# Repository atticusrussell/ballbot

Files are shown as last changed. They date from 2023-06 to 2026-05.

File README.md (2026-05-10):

# BallBot




A 4WD differential-drive robot running ROS 2 Humble that detects pickleballs on a court, navigates to them, picks them up with an onboard 6-DOF arm, and returns them to a base station — all while staying outside the court boundary so it doesn't get stepped on.

The original v1 platform paired a Raspberry Pi 4 with a Teensy 4.1 (motor/encoder/IMU via [linorobot2](https://github.com/linorobot/linorobot2)), an RPLIDAR A1, and a USB webcam. The v2 redesign in progress swaps in a Jetson Orin Nano Super, a DOFBOT-SE 6-DOF arm, and an rpicam3.

**Status**: v2 in active development. See:
- [`docs/ARCHITECTURE.md`](docs/ARCHITECTURE.md) — system design, node graph, TF tree, open architectural questions
- [`docs/ROADMAP.md`](docs/ROADMAP.md) — milestone breakdown
- [GitHub Project: Ballbot](https://github.com/users/atticusrussell/projects/6) — live progress

## Hardware

#### Front view


#### Side view


#### Rear top view


#### Initial construction


### v1 part list

| | Part |
| --| --|
|1| [Raspberry Pi 4 (4 GB)](https://www.raspberrypi.com/products/raspberry-pi-4-model-b/) — *being replaced by Jetson Orin Nano Super in v2*|
|2| [AmazonBasics 128 GB SD Card](https://www.amazon.com/dp/B08TJRVWV1)|
|3| [Yahboom Aluminum 4WD ROS Robot Car Chassis](https://category.yahboom.net/collections/a-chassis-bracket/products/ros-chassis)|
|4| [L298N Motor Drivers](https://www.amazon.com/dp/B07BK1QL5T)|
|5| [DFRobot DC-DC Power Module 25W DFR0205](https://www.digikey.com/en/products/detail/dfrobot/DFR0205/6588491)|
|6| [Screw-down Terminal Block Strips](https://www.amazon.com/dp/B08V4W637Q)|
|7| [RPLIDAR A1](https://www.slamtec.com/en/Lidar/A1)|
|8| [GeeekPi Fan Hat with OLED](https://www.amazon.com/dp/B09MVL8BWQ)|
|9| Teensy 4.1 (running [linorobot2_hardware](https://github.com/linorobot/linorobot2_hardware))|
|10| Various standoffs, wires, and crimped connectors|

### v2 additions (in progress)

- Jetson Orin Nano Super (compute upgrade)
- DOFBOT-SE 6-DOF arm + gripper (manipulation)
- Raspberry Pi Camera Module 3 (CSI, replacing the USB webcam)

See `ARCHITECTURE.md` for the full v2 hardware story including the open question on whether to bypass the DOFBOT STM32 expansion board and drive it directly over I2C from the Orin.

## Development

The project builds and runs in the VSCode devcontainers under `.devcontainer/`. Pick the variant matching your host:

- `linux-gpu/` — Linux host with NVIDIA GPU
- `wsl-gpu/` — WSL 2 with GPU passthrough

For GPU passthrough you'll first need the [NVIDIA Container Toolkit](https://docs.nvidia.com/datacenter/cloud-native/container-toolkit/latest/install-guide.html).

## Acknowledgments

- [Allison Thackston](https://github.com/athackst/vscode_ros2_workspace) — workspace template
- [Articulated Robotics](https://articulatedrobotics.xyz/) — tutorials
- [Lidarbot](https://github.com/TheNoobInventor/lidarbot)
- [linorobot2](https://github.com/linorobot/linorobot2) and [linorobot2_hardware](https://github.com/linorobot/linorobot2_hardware) — base platform
- [ros2_rover](https://github.com/mgonzs13/ros2_rover/)

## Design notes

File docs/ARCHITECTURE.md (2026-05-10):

# BallBot v2 Architecture

Reference architecture for the v2 redesign — pickleball ball-retrieval robot with onboard arm, swap from RPi 4 to Jetson Orin Nano Super, indoor + outdoor (court) operation.

This document is the source of truth for system structure. Per-phase task tracking lives in GitHub Issues / Milestones.

> **Naming policy**: the robot's name in prose is **BallBot**, and ROS packages use the `ballbot_` prefix (`ballbot_description`, `ballbot_navigation`, etc.).

---

## 1. System overview

The robot is a 4WD differential-drive base with a 6-DOF arm + gripper mounted on top. It localizes against a 2D lidar map indoors, and against pickleball-court line geometry outdoors (where lidar fails). A learned object detector finds pickleballs in the camera feed; a Behavior Tree orchestrates "find ball → drive to ball → grasp → return to base" while respecting a court keep-out polygon.

```mermaid
flowchart LR
    subgraph Perception
        CAM[Chassis camera] --> DET[Pickleball detector<br/>YOLO + TensorRT]
        CAM --> VO[Visual odometry<br/>court-line PnP]
        EIH[Eye-in-hand camera] --> VS[Visual servoing]
        LIDAR[RPLIDAR A1] --> SLAM[SLAM Toolbox / AMCL]
    end

    subgraph Localization
        SLAM --> EKF
        VO --> EKF
        WHEEL[Wheel odom + IMU] --> EKF[robot_localization EKF]
    end

    subgraph Planning
        EKF --> NAV[nav2 stack]
        DET --> BT[Behavior Tree]
        COURT[Court polygon publisher] --> NAV
        BT --> NAV
        BT --> ARM[Arm action server]
    end

    subgraph Control
        NAV --> TWIST[twist_mux]
        TWIST --> BASE[linorobot2_base / Teensy]
        VS --> ARM
        ARM --> SERVOS[DOFBOT-SE servos]
    end
```

---

## 2. Node graph + per-phase deltas

### Baseline (current state, post-revival)

```mermaid
flowchart LR
    teensy[linorobot_base<br/>Teensy] -->|/odom_raw| ekf[ekf_filter_node]
    imu[/imu/data/] --> ekf
    ekf -->|/odom + tf odom→base_link| nav[nav2]
    lidar[rplidar_node] -->|/scan| slam[slam_toolbox<br/>or amcl]
    slam -->|map→odom tf| nav
    nav -->|/cmd_vel| mux[twist_mux]
    joy[joy_teleop] -->|/cmd_vel_joy| mux
    mux -->|/cmd_vel_muxed| teensy
    cam[v4l2_camera] -->|/camera/image_raw| balltrack[ball_tracker<br/>color-blob, legacy]
```

### Adds in M1A/M1B (sim + real nav)

No new nodes — just tuning + map. nav2 + AMCL come up reliably.

### Adds in M2A/M2B (detector)

```mermaid
flowchart LR
    cam[/camera/image_raw/] --> detector[pickleball_detector<br/>YOLO TensorRT]
    detector -->|/pickleball/detections<br/>vision_msgs/Detection2DArray| projector[detection_projector]
    projector -->|/pickleball/poses<br/>geometry_msgs/PoseArray<br/>frame: map| bt[Behavior Tree]
```

`detection_projector` lifts 2D pixel detections to 3D poses on the floor plane using known camera extrinsics (no depth cam needed for a ball known to be ground-level).

`ball_tracker` (legacy) stays alongside as a fallback / tuning aid; new BT consumes from `pickleball_detector`.

### Adds in M3A/M3B (visual odometry + court)

```mermaid
flowchart LR
    cam[/camera/image_raw/] --> lines[court_line_detector<br/>Canny + Hough]
    lines --> matcher[court_pose_estimator<br/>line geometry → PnP]
    matcher -->|/court/pose_correction<br/>PoseWithCovarianceStamped| ekf
    matcher -->|/court/polygon<br/>PolygonStamped, frame: map| keepout[nav2 KeepoutFilter]
    matcher --> bt
```

VO output is fused into the existing EKF as a pose-correction source (loose coupling). The court polygon is published as a static-layer costmap filter — nav2 plans around it natively.

### Adds in M4A/M4B (manipulation)

```mermaid
flowchart LR
    eih[/eye_in_hand/image_raw/] --> servo[visual_servo_controller<br/>IBVS or PBVS]
    servo --> arm[arm_action_server<br/>DOFBOT driver]
    bt --> arm
    detector -.feature target.-> servo
```

### Adds in M5 (final integration)

No new nodes — BT v3 reaches its full form, ties everything together.

---

## 3. TF frame tree

Target tree after v2 design (M0 deliverable). New frames in **bold**.

```
map
└── odom                            [from EKF]
    └── base_link
        ├── lidar_link
        ├── chassis_camera_link
        ├── imu_link
        ├── wheel_{fl,fr,rl,rr}_link
        └── arm_base_link           ← new in v2
            └── shoulder_link       ← new in v2
                └── upper_arm_link  ← new in v2
                    └── forearm_link← new in v2
                        └── wrist_link ← new in v2
                            └── gripper_link ← new in v2
                                ├── eye_in_hand_camera_link ← new in v2
                                └── depth_camera_link ← placeholder, zero-mass
```

Notes:
- `map` → `odom` published by AMCL (indoor) or by VO fusion (outdoor at court).
- `odom` → `base_link` published by `ekf_filter_node`.
- Static transforms for sensor mountings live in URDF.
- `eye_in_hand_camera_link` calibration to `gripper_link` is hand-eye calibration (Phase 4).

---

## 4. Topic + message contracts

Load-bearing custom topics. Standard ROS topics (`/scan`, `/odom`, `/cmd_vel`, `/tf`, etc.) follow ROS conventions and aren't documented here.

| Topic | Message type | Publisher | Subscribers | Notes |
|---|---|---|---|---|
| `/pickleball/detections` | `vision_msgs/Detection2DArray` | `pickleball_detector` | `detection_projector` | Per-frame 2D bounding boxes + confidence |
| `/pickleball/poses` | `geometry_msgs/PoseArray` | `detection_projector` | BT, RViz | Ball positions in `map` frame, ground-plane projected |
| `/court/polygon` | `geometry_msgs/PolygonStamped` | `court_pose_estimator` | nav2 KeepoutFilter, BT | Court-edge polygon in `map` frame, defines keep-out |
| `/court/pose_correction` | `geometry_msgs/PoseWithCovarianceStamped` | `court_pose_estimator` | `ekf_filter_node` | VO pose against court lines, fused into EKF |
| `/bt/state` | `std_msgs/String` (custom later) | `behavior_tree_navigator` | logs, RViz panel | Current BT node + status |
| `/grasp/target_pose` | `geometry_msgs/PoseStamped` | BT | `visual_servo_controller` | Pose of target ball in `gripper_link` approach frame |
| `/arm/joint_states` | `sensor_msgs/JointState` | DOFBOT driver | RViz, MoveIt | Standard arm state |

DDS profile remains FastDDS with the custom XML at `ballbot_base/config/fastrtps.xml` (see existing `bringup.launch.py`).

---

## 5. Behavior Tree decomposition

Each phase ends with a BT extension. The BT lives in a new package (suggested: `ballbot_behavior`) and uses `nav2_behavior_tree` for action plumbing.

### BT v0 — end of M1B
"Drive to a point and come home."

```mermaid
flowchart TD
    root[Sequence] --> nav1[NavToPose<br/>target=hardcoded]
    root --> nav2[NavToPose<br/>target=base_pose]
```

### BT v1 — end of M2B

"Find a ball and drive to it; come home."

```mermaid
flowchart TD
    root[Sequence] --> wait[WaitForBallDetection<br/>topic: /pickleball/poses]
    root --> filter[FilterClosestBall]
    root --> nav1[NavToPose<br/>target=ball approach pose]
    root --> nav2[NavToPose<br/>target=base_pose]
```

### BT v2 — end of M3B

"Same, but only fetch balls outside the court polygon."

```mermaid
flowchart TD
    root[Sequence] --> wait[WaitForBallDetection]
    root --> filterOut[FilterBallsOutsideCourt<br/>uses /court/polygon]
    root --> filter[FilterClosestBall]
    root --> nav1[NavToPose]
    root --> nav2[NavToPose<br/>target=base_pose]
```

The keep-out is enforced two ways: (a) **at the planner**, via the static-layer costmap filter — robot physically can't enter the court area; and (b) **at the BT**, via `FilterBallsOutsideCourt` — robot doesn't even *try* to fetch balls that are on the court. Defense in depth.

### BT v3 — end of M4B

"Pick up the ball and drop it at base."

```mermaid
flowchart TD
    root[Sequence] --> wait[WaitForBallDetection]
    root --> filterOut[FilterBallsOutsideCourt]
    root --> filter[FilterClosestBall]
    root --> nav1[NavToPose<br/>target=ball approach pose]
    root --> grasp[GraspBall<br/>visual servoing]
    root --> nav2[NavToPose<br/>target=base_pose]
    root --> drop[DropBall]
```

Failure handling (retry, timeout, give-up) added as decorators in M5.

---

## 6. Deployment topology

Compute target: **Jetson Orin Nano Super Developer Kit** (67 INT8 TOPS, 8 GB LPDDR5, 102 GB/s, 7–25 W). This is generations beyond the original Jetson Nano B01 — single-host topology is comfortable.

```mermaid
flowchart TB
    subgraph teensy[Teensy 4.1]
        microros[micro-ROS<br/>linorobot2_hardware]
    end

    subgraph jetson[Jetson Orin Nano Super]
        ros2[ROS 2 Humble]
        nav[nav2 + AMCL]
        det[YOLO + TensorRT]
        bt[Behavior Tree]
        vs[Visual servoing]
        vo[Court VO]
        ekf[EKF]
    end

    subgraph stm32[DOFBOT-SE STM32 expansion board]
        armfw[Servo control firmware]
    end

    teensy <-->|USB serial| jetson
    rplidar[RPLIDAR A1] -->|USB| jetson
    rpicam[rpicam3<br/>IMX708 chassis cam] -->|CSI| jetson
    eih[Eye-in-hand USB camera<br/>DOFBOT 3MP module] -->|USB| jetson
    jetson <-->|USB serial| stm32
    stm32 -->|servo bus| servos[6 DOF arm + gripper]
```

- **Teensy 4.1**: motor PWM, encoder reading, IMU reading, `cmd_vel` consumer, `odom_raw` producer. Unchanged from v1.
- **DOFBOT-SE STM32 expansion board**: platform-agnostic abstraction layer for arm control. USB-serial boundary keeps the arm portable across host computers. **Not bypassed** — bypassing turns this into a firmware project.
- **Jetson Orin Nano Super**: everything else. Replaces RPi 4.
- The RPi 4 is retired in v2. With Orin Nano Super's compute headroom, distributed compute (RPi 4 as sidecar) is no longer needed for performance reasons, though it remains an option as a fun side experiment.

---

## 7. Package layout (target)

| Package | Role | Status |
|---|---|---|
| `ballbot_description` | URDF, meshes, onshape-to-robot pipeline | major rework in **M0.1** (resurrect catbot_description CAD pipeline + simplified collisions); v2 design changes in M0.2 |
| `ballbot_base` | Base driver config (linorobot2 fork), EKF, twist_mux | exists, minimal v2 changes |
| `ballbot_bringup` | Launch files for real + sim | exists, extended per phase |
| `ballbot_gazebo` | Sim worlds, plugins | exists, new pickleball court world in M3A; may absorb `obstacles.world` from `archive/catbot_simulation` |
| `ballbot_navigation` | nav2 + AMCL config + maps | exists, retuned in M1A/M1B |
| `ballbot_vision` | Detector node + dataset tools | exists, gains YOLO + TensorRT in M2 |
| `ballbot_perception` (new) | Court line detection, VO, court polygon publisher | M3A |
| `ballbot_manipulation` (new) | Visual servoing, arm action server, grasp | M4A |
| `ballbot_behavior` (new) | Behavior tree XMLs + custom BT nodes | M1B onward |
| `ball_tracker` (legacy) | Color-blob detector | retained as fallback / tuning aid |
| `archive/catbot_description` | Onshape-to-robot pipeline + CAD-derived URDF | **source material for M0.1 migration**; archive can be deleted after merge |
| `archive/catbot_simulation` | Older standalone Gazebo launch + `obstacles.world` | source for `obstacles.world` only; rest superseded by `ballbot_gazebo` |

---

## 8. Open architectural questions

These are explicit unresolved decisions. Each will move out of this section as it's decided (with rationale captured wherever the decision lives in the doc).

1. **Depth camera — yes or no, where?** Skip in v2 per current plan; mono visual servoing for manipulation. Add only if mono stalls. If added, **mounts on the arm (eye-in-hand)**, not chassis — chassis depth gives marginal nav benefit, eye-in-hand depth massively simplifies grasp. CAD: leave clearance + mounting holes on the arm; URDF: leave a `depth_camera_link` frame defined with zero mass placeholder. *Status: tentatively no, eye-in-hand if added.*
2. **Visual servoing — IBVS or PBVS?** IBVS = simpler, image-space loop closure, robust to camera calibration error, doesn't need explicit 3D pose estimate. PBVS = explicit 3D loop, easier to integrate with motion planning. Decide before M4A. *Status: open.*
3. **nav2 controller — DWB or MPPI?** MPPI is newer, smoother, samples thousands of trajectory rollouts. With Orin Nano Super's compute, MPPI is no longer compute-prohibitive. DWB is the safer-tested default. Decide during M1A. *Status: open, leaning MPPI.*
4. **VO + AMCL fusion strategy** — Fuse VO always (loose EKF coupling), or switch on/off based on environment (indoor=AMCL, outdoor=VO)? Loose fusion is simpler; switching is more correct but adds state. *Status: tentatively loose fusion always.*
5. ~~**Compute topology — single Jetson or distributed?**~~ **CLOSED**: single Jetson Orin Nano Super. 67 INT8 TOPS comfortably handles nav + inference + servoing simultaneously. Distributed remains a fun side experiment, not a requirement.
6. **Detector replacement** — Does the new YOLO detector replace `ball_tracker` entirely, or live alongside? Currently planned alongside (legacy as fallback / tuning aid). Revisit after M2B confidence. *Status: alongside.*
7. **Eye-in-hand camera type** — DOFBOT-SE ships with a USB camera + bracket. Orin Nano Super CSI port is available and supports rpicam3. USB is simpler / arm-supplied; CSI gives lower latency + better quality. *Status: tentatively use the supplied USB cam to start, swap if quality drives a need.*
8. **Map storage strategy** — Single static apartment map, or session-rebuilt? Pickleball court geometry is *known*, so the court "map" is just the published polygon, not a SLAM map. Indoor map is static (saved). *Status: indoor static, outdoor geometric.*
9. **Search behavior between fetches** — How does the robot wait for a ball to come into view? Options: (a) park at a chosen vantage point, chassis cam pointed at court; (b) low-rate patrol along the sideline; (c) park + active pan/tilt scan with a 2-DOF camera platform (see #10). Doesn't change architecture — only the BT search subtree. *Status: deferred; pick (a) park-at-corner as v1 placeholder.*
10. **Pan/tilt camera platform** — Optional 2-DOF servo platform for the chassis camera. Battery-cheap (servos <1W) vs. driving (motors 5-20W) — could change the search strategy from patrol to park-and-scan. Would add a `pan_tilt_controller` node + `gimbal_link` TF frame *if* installed. *Status: deferred. No URDF placeholder reserved — adding the link later is a 5-minute change, no need to carry the complexity now.*
11. **DOFBOT-Pro firmware/code reuse** — DOFBOT-Pro is a parallel SKU with same expansion board and confirmed Orin Nano Super support. **Confirmed**: Yahboom ships a complete URDF (`SystemFile_OrinNANOSUPER`) plus ROS code for this configuration. *Status: closing — submodule both `dofbot-pro` and `dofbot-se` into `third_party/`, compose the Pro URDF for the arm in v2 instead of re-CADing.*

12. **STM32 bypass: direct I2C from Orin to expansion board** — DOFBOT-Pro evidence: the Orin Nano Super connects directly to the arm expansion board via 2 GPIO pins (I2C) over a ribbon cable, bypassing USB serial entirely. Trade-offs: lower latency, fewer cables, no host-portable abstraction layer. The DOFBOT-SE STM32 path remains as a fallback. *Status: investigation issue in M0.2; decision must precede M0.2 CAD work since it affects cable routing and plate cutouts.*

---

## 9. Decision log

- **2026-05-10** — Compute target is Jetson Orin Nano Super (not Jetson Nano B01). 67 INT8 TOPS, 8 GB. Closes open question 5 (single-host topology).
- **2026-05-10** — DOFBOT-SE STM32 expansion board kept in the loop; not bypassed. USB-serial is the host-arm boundary. Reason: keep the arm portable, avoid a firmware project as a side quest.
- **2026-05-10** — Eye-in-hand camera placement, not chassis, if depth ever gets added. Reason: chassis depth gives marginal nav benefit; eye-in-hand depth massively simplifies grasp.
- **2026-05-10** — Search-behavior decision deferred. v1 placeholder: park-at-corner with chassis cam pointed at court. BT search subtree is the only thing that changes when this is decided.
- **2026-05-10** — Pan/tilt gimbal: deferred entirely, no URDF placeholder. Adding the link later is trivial; carrying it now is premature complexity.
- **2026-05-10** — M0 split into M0.1 (URDF foundation migration from `archive/catbot_description`) and M0.2 (v2 CAD design changes). Reason: keeps the v2 design changes a "rerun the import" instead of "rebuild the URDF system," and protects against future CAD churn.
- **2026-05-10** — Robot's prose name is "BallBot." All `brobot_*` ROS packages renamed to `ballbot_*` to match (reverses an earlier same-day call to defer the rename).
- **2026-05-10** — Yahboom DOFBOT-Pro URDF (`SystemFile_OrinNANOSUPER`) + ROS code adopted as source for the arm in v2. Re-CADing the arm in Onshape is unnecessary; compose Pro URDF + own chassis CAD instead. Closes open question 11.
- **2026-05-10** — Yahboom code distribution reality: GitHub repos host only PDFs (tutorials, courses). Source code (URDFs, ROS nodes, system images) is on Google Drive only — link in `Annex_Download_Link.txt`. Practical impact: submodule the GitHub repos for tutorial PDFs; do a manual Drive pull for code into `third_party/dofbot-pro-code/`.
- **2026-05-10** — STM32 bypass investigation slated for M0.2 (must precede CAD changes). DOFBOT-Pro firmware exists for direct Orin-to-expansion-board I2C. Decision affects cable routing.
- **2026-05-10** — `archive/catbot_description/` and `archive/catbot_simulation/` to be deleted after M0.1 merge. Git history preserves; `obstacles.world` absorbed into `ballbot_gazebo` if useful.
- **2026-05-10** — Repo layout: `third_party/` at root for code submodules (Yahboom repos); `docs/third_party/` for documentation (datasheets, tutorials). Two separate domains.
- **2026-05-10** — Roadmap moved to `docs/ROADMAP.md`. Refinement happens by editing that file, not by re-dumping in chat.

---

## 10. Glossary

- **AMCL** — Adaptive Monte Carlo Localization. Standard nav2 localizer using a particle filter against a known map.
- **BT** — Behavior Tree. Hierarchical control flow for robot autonomy. Used by nav2 natively.
- **DOFBOT-SE** — Yahboom 6-DOF servo arm + gripper.
- **EKF** — Extended Kalman Filter. Used here via `robot_localization` to fuse odometry + IMU + (later) VO.
- **IBVS / PBVS** — Image-Based / Position-Based Visual Servoing. Two flavors of arm closed-loop control from camera feedback.
- **MPPI** — Model Predictive Path Integral. nav2 controller; samples thousands of trajectory rollouts per cycle.
- **PnP** — Perspective-n-Point. Algorithm: given known 3D points and their 2D image projections, solve for camera pose.
- **TensorRT** — NVIDIA inference runtime. Required for real-time YOLO on Jetson.
- **VO** — Visual Odometry. Estimating motion / pose from a sequence of camera images.
- **YOLO** — "You Only Look Once." Object detection model family.

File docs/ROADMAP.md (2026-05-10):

# BallBot v2 Roadmap

Milestone + issue breakdown for the v2 redesign. This is the working planning doc — refine here, don't re-dump in chat.

**Companion docs**: [`ARCHITECTURE.md`](./ARCHITECTURE.md) is the source of truth for system structure. This doc is the source of truth for *what gets built when*.

**Status legend**: 🟦 not started · 🟨 in progress · 🟩 done · ⬜ deferred / open

---

## Conventions

- Each milestone gets a GitHub Milestone (native).
- Each bullet under "Issues" gets a GitHub Issue (native), tagged with the milestone.
- Each milestone gets its own feature branch (`phase/M<id>-<slug>`), PR'd to `humble` when the milestone closes.
- **Each milestone closure gets a git tag**: `m{id}-complete` (e.g., `m0.1-complete`, `m1a-complete`, `m4b-complete`). Tag every milestone, including prep / reading / hardware milestones, for trivial rollback to any phase boundary.
- Reading-group issues use a checklist of chapter PDFs from `docs/third_party/dofbot-tutorials/`.
- Behavior tree (BT) extension issues live at the end of their parent "B" milestone.
- HW integration milestones (M*.5) are atomic and small — green-light test only.

---

## M0.1 — URDF foundation migration 🟦
**Goal**: Resurrect `archive/catbot_description`'s onshape-to-robot pipeline into `ballbot_description` with simplified collisions. Mass-accurate v1 robot in URDF (no v2 design changes yet).
**Branch**: `phase/M0.1-urdf-foundation`
**Issues**:
- Add `onshape-to-robot` pipeline to `ballbot_description` (config.json, `moveMeshes.sh`, `urdf_newlines.py`)
- Migrate CAD-derived chassis + wheel meshes from `archive/catbot_description/meshes/`
- Replace parametric base + wheel xacros with CAD-derived URDF macros
- Configure sensors (camera, lidar, IMU) via the onshape-to-robot pipeline's `additional.xml` block
- Simplify collision shapes: switch from full mesh collision to convex hull or primitive boxes (use the alternate forms already CAD'd)
- Verify URDF spawns in Gazebo with no self-collision
- Verify TF tree clean
- Confirm mass + CoG match v1 robot
- Delete `archive/catbot_description/` and `archive/catbot_simulation/` after merge (preserve `obstacles.world` first if absorbing)
- Open PR + tag `m0.1-complete`

---

## M0.2 — v2 CAD design changes 🟦
**Goal**: Update Onshape doc with v2 changes (arm mount, Jetson, depth cam placeholder), bump document version, rerun import. Should be "run the script" not "rebuild the system."
**Branch**: `phase/M0.2-v2-design`
**Issues**:
- **Investigate STM32 bypass: direct I2C from Orin to expansion board** (study DOFBOT-Pro firmware + URDF; decide before CAD changes since it affects cable routing + plate cutouts)
- Compose Yahboom DOFBOT-Pro arm URDF into BallBot URDF (skip re-CADing the arm)
- Design top plate in Onshape: arm mount + Jetson Orin Nano Super footprint + clearance for existing components
- Add Jetson + heatsink as mass block in CAD
- Add depth camera as suppressed part (zero density, mounting holes only)
- Bump Onshape document version in `config.json`
- Rerun onshape-to-robot import
- Verify v2 URDF spawns in Gazebo, no self-collision
- Sanity-check inertia + CoG against estimated v2 numbers
- Open PR + tag `m0.2-complete`

---

## M1A — Sim Nav 🟦
**Goal**: 48/50 random nav goals succeed in multi-room sim apartment.
**Branch**: `phase/M1A-sim-nav`
**Issues**:
- Build multi-room sim world (4-5 rooms, doorways, clutter)
- Update `ballbot_gazebo` launch to spawn v2 URDF in new world
- Configure nav2 params yaml for v2 footprint + dynamics
- Generate sim map via `slam_toolbox`
- Read AMCL / particle filter background (Probabilistic Robotics ch 8 or equivalent)
- Tune local + global costmap inflation
- Choose controller (DWB vs MPPI) — leaning MPPI given Orin compute
- Tune controller for v2 dynamics
- Implement 50-random-goal benchmark script
- Iterate tuning until ≥48/50

---

## M1.5 — HW Revival 🟦
**Goal**: Existing real robot powers up, all ROS nodes green.
**Branch**: `phase/M1.5-hw-revival`
**Issues**:
- Inspect robot from storage for damage
- Test/replace battery, validate voltage rail
- Re-flash Teensy with current `linorobot2_hardware`
- Boot RPi 4 (interim host), restore wifi + ssh
- Diagnose and fix the cyclonedds env var issue
- Bringup smoke test (motors, lidar, IMU, camera all publish)

---

## M1B — Real Nav 🟦
**Goal**: ≥9/10 RViz goals succeed in your real apartment.
**Branch**: `phase/M1B-real-nav`
**Issues**:
- Run `slam_toolbox` in apartment, save initial map
- Extend map to multi-room coverage
- Configure AMCL with saved map
- Re-tune costmaps for real RPLIDAR A1 noise
- Run 10-goal apartment benchmark from RViz
- Iterate until ≥9/10
- **BT v0**: nav-to-hardcoded-pose + return-to-base + handle nav failure
- Validate BT v0 with 5 successful cycles

---

## Reading-A — Pre-Detector 🟦
**Goal**: Foundational CV reading before training a detector.
**Issues**:
- Read DOFBOT course 07 (OpenCV course) — 18-chapter checklist
- Read DOFBOT course 08 (AI vision basic) — 6-chapter checklist

---

## M2A — Sim Detector 🟦
**Goal**: ≥90% mAP on synthetic test set.
**Branch**: `phase/M2A-sim-detector`
**Issues**:
- Spawn pickleballs in Gazebo with randomized poses
- Implement domain randomization (lighting, court color, distractors)
- Build auto-label image capture pipeline (1-2k images)
- Set up YOLO training env on the RTX 3080
- Train YOLOv8 (size: m or l, given Orin compute) on synthetic dataset
- Eval on held-out synthetic test set, iterate to ≥90% mAP
- Sanity-test detector node live in Gazebo

---

## M2.5 — HW Compute + Cam 🟦
**Goal**: Jetson Orin Nano Super + rpicam3 swap, dummy inference passes.
**Branch**: `phase/M2.5-hw-compute-cam`
**Issues**:
- Acquire Jetson Orin Nano Super carrier + PSU (if not ready)
- Acquire rpicam3 (if not ready)
- Mount Jetson on new top plate
- Wire Jetson power (rail or independent BEC)
- Migrate ROS workspace to Jetson, build all packages
- Connect rpicam3 via CSI, verify libcamera + ROS image publisher
- Smoke test: detector node runs on Jetson with live cam

---

## M2B — Real Detector 🟦
**Goal**: ≥30fps on Orin, ≥90% precision in apartment 0.5-3m range.
**Branch**: `phase/M2B-real-detector`
**Issues**:
- Capture 200-500 real pickleball photos (varied lighting)
- Fine-tune sim-trained model on real data
- Convert model to TensorRT
- Deploy detector node on Orin, measure fps
- Validate ≥90% precision in apartment
- Implement detection_projector node (2D pixel → 3D ground-plane pose)
- **BT v1**: detect → nav-to-ball → return
- Validate BT v1 with 5 cycles in apartment

---

## Reading-B — Pre-VO 🟦
**Goal**: Line/feature/optical-flow reading before VO.
**Issues**:
- Read DOFBOT course 12 (ROS+OpenCV) — selected chapters checklist (Hough lines, edge, contour, feature tracking, optical flow)

---

## M3A — Sim VO + Court Keep-Out 🟦
**Goal**: <10cm pose error over 20m sim court traversal; keep-out costmap working.
**Branch**: `phase/M3A-sim-vo`
**Issues**:
- Build sim pickleball court world (lines, fences)
- Implement line detection node (Canny + Hough)
- Implement court geometry matcher (detected lines → known layout)
- Solve PnP for camera pose against court
- Fuse VO with wheel odometry via `robot_localization` EKF
- Validate <10cm pose error over 20m sim traversal
- Publish court polygon as nav2 static-layer costmap (keep-out filter)
- Verify nav2 respects keep-out in sim

---

## M3B — Real VO at Court 🟦
**Goal**: <30cm drift on real court; field-trip data captured.
**Branch**: `phase/M3B-real-vo`
**Issues**:
- Field trip 1: record bag of camera/lidar/odom on real court
- Run VO pipeline offline against bag, plot trajectory
- Validate <30cm drift over court length
- Tune line detector for real lighting/shadows
- Field trip 2: live VO at court
- **BT v2**: BT v1 + enforce court keep-out polygon (via `FilterBallsOutsideCourt` BT node + nav2 keepout filter)
- Validate BT v2 with 3 cycles outside boundary

---

## Reading-C — Pre-Manipulation 🟦
**Goal**: Kinematics, control, MoveIt2 fundamentals before manipulation.

Prefer DOFBOT-Pro Orin-Super tutorials (ROS 2 native, MoveIt2) over DOFBOT-SE (ROS 1) where chapters overlap.

**Issues**:
- Read DOFBOT-Pro `23.For_JetsonORIN_SUPER_JetPack6.2/12. MoveIt Case Study/` — full 10-chapter checklist (MoveIt2 config, IK design, trajectory planning, collision detection)
- Read DOFBOT-Pro `23.For_JetsonORIN_SUPER_JetPack6.2/21. ROS2 basic course/21.ROS2 URDF model.pdf`
- Read DOFBOT-SE course 06 (Basic control) — 12-chapter checklist (servo control fundamentals, hardware-level)
- Read DOFBOT-SE course 09 (AI vision tracking, ch 1: PID basics) — single-chapter focus
- Read DOFBOT-Pro course 11 (3D Robotic Arm Control and Inverse Kinematics) — 2-chapter checklist

---

## M4A — Sim Manipulation (eye-in-hand mono) 🟦
**Goal**: Sim arm grasps ball ≥80% in sim.
**Branch**: `phase/M4A-sim-manip`
**Issues**:
- Add eye-in-hand camera to URDF on arm end-effector
- Verify camera publishes in Gazebo
- Implement visual servoing controller (IBVS or PBVS — pick + justify)
- Configure hand-eye calibration in sim
- Implement grasp policy (approach pose → close gripper)
- Spawn 50 random-pose balls, log success rate
- Iterate to ≥80%

---

## M4.5 — HW Arm 🟦
**Goal**: Arm physically mounted, calibrated, reachable.
**Branch**: `phase/M4.5-hw-arm`
**Issues**:
- Physically mount DOFBOT-SE (or bypassed config from M0.2 decision) to top plate
- Run servo calibration sequence
- Verify arm joints respond to ROS commands (over USB or I2C per M0.2 decision)
- Verify reachable workspace matches URDF
- Mount eye-in-hand camera on arm
- Hand-eye calibration on real arm
- Smoke test: arm moves to commanded Cartesian pose

---

## M4B — Real Manipulation 🟦
**Goal**: Real arm grasps real pickleball ≥80% on bench.
**Branch**: `phase/M4B-real-manip`
**Issues**:
- Re-tune visual servoing for real arm dynamics
- Bench: 50 grasp attempts on real ball at known poses
- Iterate to ≥80%
- **BT v3**: BT v2 + grasp + drop at base
- Validate BT v3 with 3 successful pickup-and-drop cycles

---

## M5 — Final Integration + Court Demo 🟦
**Goal**: ≥3 balls picked at real court, demo video captured.
**Branch**: `phase/M5-court-demo`
**Issues**:
- Full pipeline sim test: 3-ball court demo end-to-end
- Field trip 3: full pipeline at real court
- Iterate on real-world failure modes
- Capture demo video (multi-angle, edited)
- Write project page / portfolio post

---

## Tutorial reading sources

- DOFBOT-SE tutorials (`docs/third_party/dofbot-se/`, also a vendored copy at `docs/third_party/dofbot-tutorials/`) are **ROS 1**. Useful for fundamentals (PID, OpenCV, Linux), less useful for ROS 2 specifics.
- DOFBOT-Pro tutorials (`docs/third_party/dofbot-pro/`) include `23.For_JetsonORIN_SUPER_JetPack6.2/` with **ROS 2 native** content: MoveIt2 configuration, MoveIt2 inverse kinematics, MoveIt2 trajectory planning, ROS 2 URDF model.
- **Reading-C (Pre-Manipulation) prefers the Pro/Orin-Super tutorials** for MoveIt2 + ROS 2 chapters, falling back to SE only for fundamentals.
- Yahboom-provided source code (URDFs, ROS nodes) is at `third_party/dofbot-pro/` (Drive download) and `third_party/dofbot-se/` — separate from the docs.

## Side-quest issues

Off-roadmap fill-in work lives in GitHub issues with the `side-quest` label, no milestone, not on the project board. Pull from there when looking for a small task between phase commitments. See [open side-quests](https://github.com/atticusrussell/ballbot/issues?q=is%3Aopen+is%3Aissue+label%3Aside-quest).

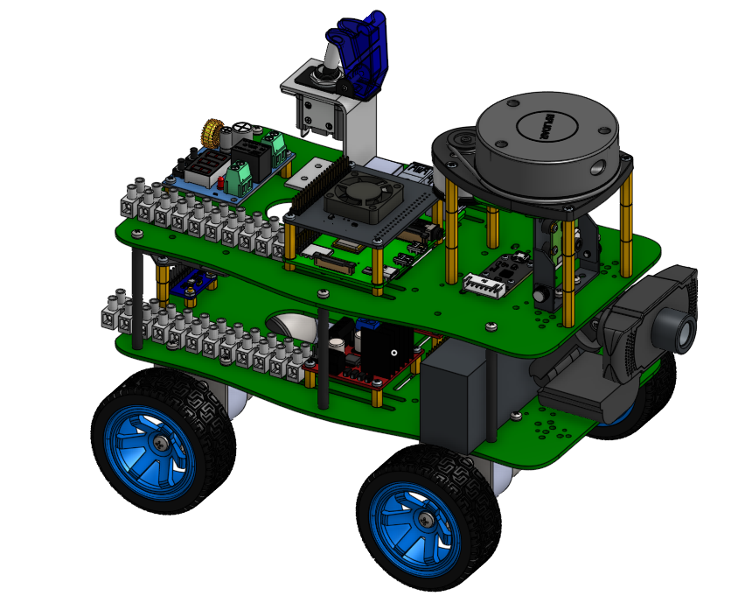
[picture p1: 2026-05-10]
docs/images/onshape-capture-isometric-2025-05-17-17-49-17.png

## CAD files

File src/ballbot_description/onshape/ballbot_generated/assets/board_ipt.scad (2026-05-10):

% scale(1000) import("board_ipt.stl");

// Sketch PureShapes 2
multmatrix([[1.0, 0.0, 0.0, 0.0], [0.0, -1.0, 0.0, 0.0], [0.0, 0.0, -1.0, 0.0], [0.0, 0.0, 0.0, 1.0]]) {
thickness = 2.000000;
translate([0, 0, -thickness]) {
  translate([-5.500000, 10.250000, 0]) {
    cylinder(r=1.500000,h=thickness);
  }
  translate([-5.500000, -10.250000, 0]) {
    cylinder(r=1.500000,h=thickness);
  }
  translate([6.000000, -11.430000, 0]) {
    cylinder(r=0.500000,h=thickness);
  }
  translate([6.000000, -8.890000, 0]) {
    cylinder(r=0.500000,h=thickness);
  }
  translate([6.000000, -6.350000, 0]) {
    cylinder(r=0.500000,h=thickness);
  }
  translate([6.000000, -3.810000, 0]) {
    cylinder(r=0.500000,h=thickness);
  }
  translate([6.000000, -1.270000, 0]) {
    cylinder(r=0.500000,h=thickness);
  }
  translate([6.000000, 1.270000, 0]) {
    cylinder(r=0.500000,h=thickness);
  }
  translate([6.000000, 3.810000, 0]) {
    cylinder(r=0.500000,h=thickness);
  }
  translate([6.000000, 6.350000, 0]) {
    cylinder(r=0.500000,h=thickness);
  }
  translate([6.000000, 8.890000, 0]) {
    cylinder(r=0.500000,h=thickness);
  }
  translate([6.000000, 11.430000, 0]) {
    cylinder(r=0.500000,h=thickness);
  }
}
}

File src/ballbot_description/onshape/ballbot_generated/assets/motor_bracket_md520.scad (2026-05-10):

% scale(1000) import("motor_bracket_md520.stl");

// Sketch PureShapes 2
multmatrix([[1.0, 0.0, 2.182496894510885e-63, 4.419556211384542e-62], [-1.2881473799058362e-94, 1.0, 5.90217279642233e-32, 1.1951899912755218e-30], [-2.182496894510885e-63, -5.90217279642233e-32, 1.0, 20.25], [0.0, 0.0, 0.0, 1.0]]) {
thickness = 2.000000;
translate([0, 0, -thickness]) {
  translate([20.000000, 1.500000, 0]) {
    rotate([0, 0, 180.0]) {
      cube([40.000000, 3.500000, thickness]);
    }
  }
}
}

// Sketch PureShapes 2
multmatrix([[1.0, 0.0, 4.9303806576313194e-32, 9.860761315262639e-32], [4.9303806576313194e-32, 5.90217279642233e-32, -1.0, -2.0], [-2.909995859347841e-63, 1.0, 5.90217279642233e-32, 1.180434559284466e-31], [0.0, 0.0, 0.0, 1.0]]) {
thickness = 2.000000;
translate([0, 0, -thickness]) {
  translate([-20.000000, 16.750000, 0]) {
    rotate([0, 0, 0.0]) {
      cube([40.000000, 3.500000, thickness]);
    }
  }
}
}

// Sketch PureShapes 2
multmatrix([[1.0, 0.0, 4.9303806576313194e-32, 9.860761315262639e-32], [4.9303806576313194e-32, 5.90217279642233e-32, -1.0, -2.0], [-2.909995859347841e-63, 1.0, 5.90217279642233e-32, 1.180434559284466e-31], [0.0, 0.0, 0.0, 1.0]]) {
thickness = 2.000000;
translate([0, 0, -thickness]) {
  translate([20.000000, 16.750000, 0]) {
    rotate([0, 0, 180.0]) {
      cube([40.000000, 37.000000, thickness]);
    }
  }
}
}

// Sketch PureShapes 2
multmatrix([[1.0, 0.0, 2.182496894510885e-63, 4.419556211384542e-62], [-1.2881473799058362e-94, 1.0, 5.90217279642233e-32, 1.1951899912755218e-30], [-2.182496894510885e-63, -5.90217279642233e-32, 1.0, 20.25], [0.0, 0.0, 0.0, 1.0]]) {
thickness = 2.000000;
translate([0, 0, -thickness]) {
  translate([-20.000000, 1.500000, 0]) {
    rotate([0, 0, 0.0]) {
      cube([40.000000, 18.000000, thickness]);
    }
  }
}
}

// Sketch PureShapes 2
multmatrix([[1.0, 0.0, 2.182496894510885e-63, 4.419556211384542e-62], [-1.2881473799058362e-94, 1.0, 5.90217279642233e-32, 1.1951899912755218e-30], [-2.182496894510885e-63, -5.90217279642233e-32, 1.0, 20.25], [0.0, 0.0, 0.0, 1.0]]) {
thickness = 2.000000;
translate([0, 0, -thickness]) {
  translate([0.000000, 19.500000, 0]) {
    cylinder(r=20.000000,h=thickness);
  }
}
}

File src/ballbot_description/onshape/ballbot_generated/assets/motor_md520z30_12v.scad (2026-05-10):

% scale(1000) import("motor_md520z30_12v.stl");

// Sketch PureShapes 15
multmatrix([[-1.0, 0.0, -1.75355697474982e-17, -7.452617142686736e-16], [-1.75355697474982e-17, 1.86957266710559e-16, 1.0, 42.5], [3.278402190204631e-33, 1.0, -1.86957266710559e-16, -7.945683835198759e-15], [0.0, 0.0, 0.0, 1.0]]) {
thickness = 15.000000;
translate([0, 0, -thickness]) {
  translate([-0.000000, -7.000000, 0]) {
    cylinder(r=3.000000,h=thickness);
  }
  translate([-0.000000, -7.000000, 0]) {
    cylinder(r=3.000000,h=thickness);
  }
}
}

// Sketch PureShapes 6
multmatrix([[-1.0, 0.0, -1.75355697474982e-17, -4.822281680562006e-16], [-1.75355697474982e-17, 1.86957266710559e-16, 1.0, 27.5], [3.278402190204631e-33, 1.0, -1.86957266710559e-16, -5.141324834540372e-15], [0.0, 0.0, 0.0, 1.0]]) {
thickness = 6.000000;
translate([0, 0, -thickness]) {
  translate([-0.000000, -7.000000, 0]) {
    cylinder(r=6.000000,h=thickness);
  }
  translate([-0.000000, -7.000000, 0]) {
    cylinder(r=6.000000,h=thickness);
  }
}
}

// Sketch PureShapes 25.7
multmatrix([[1.0, 0.0, 1.75355697474982e-17, 4.497873640233288e-16], [1.75355697474982e-17, 1.86957266710559e-16, -1.0, -25.65], [-3.278402190204631e-33, 1.0, 1.86957266710559e-16, 4.795453891125838e-15], [0.0, 0.0, 0.0, 1.0]]) {
thickness = 25.700000;
translate([0, 0, -thickness]) {
  translate([-0.000000, -0.000000, 0]) {
    cylinder(r=16.375000,h=thickness);
  }
}
}

// Sketch PureShapes 6.7
multmatrix([[1.0, 0.0, 1.75355697474982e-17, 5.663989028441918e-16], [1.75355697474982e-17, 1.86957266710559e-16, -1.0, -32.300000000000004], [-3.278402190204631e-33, 1.0, 1.86957266710559e-16, 6.0387197147510565e-15], [0.0, 0.0, 0.0, 1.0]]) {
thickness = 6.700000;
translate([0, 0, -thickness]) {
  translate([-0.000000, -0.000000, 0]) {
    cylinder(r=7.000000,h=thickness);
  }
  translate([-0.000000, -0.000000, 0]) {
    cylinder(r=7.000000,h=thickness);
  }
}
}

// Sketch PureShapes 21.5
multmatrix([[-1.0, 0.0, -1.75355697474982e-17, -3.7701474957121127e-16], [-1.75355697474982e-17, 1.86957266710559e-16, 1.0, 21.5], [3.278402190204631e-33, 1.0, -1.86957266710559e-16, -4.019581234277018e-15], [0.0, 0.0, 0.0, 1.0]]) {
thickness = 21.500000;
translate([0, 0, -thickness]) {
  translate([0.000000, 0.000000, 0]) {
    cylinder(r=18.500000,h=thickness);
  }
  translate([0.000000, 0.000000, 0]) {
    cylinder(r=18.500000,h=thickness);
  }
}
}

// Sketch PureShapes 5
multmatrix([[1.0, 0.0, 1.75355697474981e-17, 5.3746521276081685e-16], [1.75355697474981e-17, 1.86957266710559e-16, -1.0, -30.65], [-3.278402190204612e-33, 1.0, 1.86957266710559e-16, 5.730240224678633e-15], [0.0, 0.0, 0.0, 1.0]]) {
thickness = 5.000000;
translate([0, 0, -thickness]) {
  translate([-9.000000, 7.000000, 0]) {
    rotate([0, 0, 180.0]) {
      cube([6.000000, 14.000000, thickness]);
    }
  }
}
}

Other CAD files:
src/ballbot_description/meshes/male_pin_header.stl
src/ballbot_description/onshape/ballbot_generated/assets/webcam_sensor.stl
src/catbot_description/meshes/collision/wheel_assm_collision.stl
src/catbot_description/meshes/visual/wheel_assm_2_visual.stl
src/catbot_description/onshape/catbot/still_chassis_assm_visual.stl
src/ballbot_description/meshes/webcam_neck.stl
src/ballbot_description/onshape/ballbot_generated/assets/rplidar_a1_head.stl
src/catbot_description/meshes/collision/still_chassis_assm_collision.stl
src/catbot_description/meshes/visual/wheel_assm_4_visual.stl
src/catbot_description/onshape/catbot/wheel_assm_4_collision.stl
src/ballbot_description/meshes/cam_3_lens_front.stl
src/ballbot_description/onshape/ballbot_generated/assets/webcam_body.stl
src/catbot_description/meshes/collision/wheel_assm_4_collision.stl
src/catbot_description/meshes/visual/wheel_assm_3_visual.stl
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

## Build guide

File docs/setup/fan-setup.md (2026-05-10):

# Fan Control Setup (52Pi Fan Expansion Board Plus)

This guide explains how to set up the fan control for the 52Pi Fan Expansion Board Plus on your Raspberry Pi. The fan control automatically adjusts based on the CPU temperature.

References:
- [Official Wiki Page (Fan section)](https://wiki.52pi.com/index.php?title=EP-0152#How_to_control_the_fan)
- [GeeekPi RPiFEBP GitHub Repo](https://github.com/geeekpi/RPiFEBP)

---

## Requirements

This guide assumes you have cloned your repository (e.g., `ballbot`) directly onto your Raspberry Pi:

```bash
git clone https://github.com/atticusrussell/ballbot.git
cd ballbot
```

---

## Installation

The installation is performed in one single step by running the provided setup script.

### Step: Run the Combined Setup Script

```bash
cd setup/scripts
sudo ./setup-fan.sh
```

This script will:

- Install the required system dependencies (`python3`, `python3-pip`, `python3-rpi.gpio`).
- Copy the fan control Python script to `/opt/ballbot`.
- Install and start the systemd service for fan control.

After running the script, the fan control will automatically monitor the CPU temperature using the script `/opt/ballbot/fan_control.py`:
- **≥ 45°C:** Fan at 100% duty cycle  
- **≥ 40°C:** Fan at 85% duty cycle  
- **Below 40°C:** Fan off

---

## Customization

If you wish to modify the behavior (e.g., adjust temperature thresholds or change the GPIO pin), edit the Python file directly:

```bash
sudo nano /opt/ballbot/fan_control.py
```

After making any changes, restart the service to apply them:

```bash
sudo systemctl restart fan.service
```

To view logs for troubleshooting:

```bash
journalctl -u fan.service -e
```

---

## Result

Once installed, your fan control service will adjust the fan speed based on the CPU temperature, ensuring efficient cooling with minimal system overhead.

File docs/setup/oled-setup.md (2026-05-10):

# OLED Display Setup (0.91 inch)

This guide walks through the process of enabling and configuring the OLED display on the 52Pi Fan Expansion Board Plus for the Raspberry Pi.

References:
- [Official Wiki Page (OLED section)](https://wiki.52pi.com/index.php?title=EP-0152#How_to_display_system_information_on_OLED_display)
- [GeeekPi RPiFEBP GitHub Repo](https://github.com/geeekpi/RPiFEBP)

---

## Requirements

This setup assumes you have cloned this repository directly onto your Raspberry Pi:

```bash
git clone https://github.com/atticusrussell/ballbot.git
cd ballbot
```

---

## Installation

Installation is split into three steps.

### Step 1: Install system dependencies (requires `sudo`)

This will install required system packages, including `raspi-config`, `i2c-tools`, and development libraries.

```bash
cd setup/scripts
sudo ./install-oled-dependencies.sh
```

---

### Step 2: Enable I2C (manual step)

Once `raspi-config` is installed, enable the I2C interface:

```bash
sudo raspi-config
# Navigate to: Interface Options -> I2C -> Enable -> YES
```

Then reboot or log out and back in so the `i2c` group membership takes effect.

---

### Step 3: Set up OLED environment (requires `sudo`)

This script sets up the Python environment and systemd service:

```bash
sudo ./setup-oled.sh
```

This script will:

- Create a virtual environment in `/opt/ballbot/venv`
- Install `luma.oled` and `psutil`
- Copy the custom OLED display script to `/opt/ballbot/system_info.py`
- Register and start a systemd service to run the display on boot

---

## Customization

Once installed, the active OLED script on your robot is located at:

```bash
/opt/ballbot/system_info.py
```

You can edit this file directly to change what’s displayed. For example:

```bash
sudo nano /opt/ballbot/system_info.py
```

After making changes, restart the service to apply them:

```bash
sudo systemctl restart oled.service
```

To check the service logs for errors:

```bash
journalctl -u oled.service -e
```

---

## Result

After setup and reboot, your OLED should display:

- CPU temperature
- IP address
- Memory usage
- Disk usage

You can customize these metrics or add your own.

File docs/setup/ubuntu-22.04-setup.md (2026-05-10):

# Ubuntu Server 22.04.3 Setup for Robot

This guide walks through the initial setup of a fresh Ubuntu Server 22.04.3 install.

---

## 1. Disable cloud-init

```bash
sudo apt purge cloud-init && sudo rm -rf /etc/cloud/
sudo touch /etc/cloud/cloud-init.disabled
```

---

## 2. Set up Wi-Fi using Netplan

Create or edit `/etc/netplan/01-netcfg.yaml`:

```yaml
network:
  version: 2
  renderer: networkd
  ethernets:
    eth0:
      dhcp4: true
      optional: true
  wifis:
    wlan0:
      dhcp4: true
      optional: true
      access-points:
        "YourSSID":
          password: "YourPassword"
```

Then run:

```bash
sudo systemctl enable --now systemd-networkd
sudo systemctl enable --now systemd-resolved

sudo netplan generate
sudo netplan apply
sudo reboot
```

---

## 3. Post-WiFi Setup

After confirming that Wi-Fi works and you've rebooted, you can run a script to complete the rest of the system configuration automatically.

### 📥 Download the script

You can download the script directly to your robot:

```bash
curl -O https://raw.githubusercontent.com/atticusrussell/ballbot/main/setup/scripts/post-wifi-setup.sh
chmod +x post-wifi-setup.sh
```

> **Tip:** Always review downloaded scripts before running them with elevated privileges.

### Run the script with sudo

```bash
sudo ./post-wifi-setup.sh
```

This will:
- Remove unattended-upgrades
- Disable periodic APT auto-updates
- Ensure SSH is enabled
- Install Avahi daemon for `.local` hostname access
- Set hostname to `rosbot`

---

### 3.1 Avahi configuration (optional)
tweak a few settings to avoid hostname changing
- manually specify `host-name`
- disable `check-response-ttl`
- 

in `/etc/avahi/avahi-daemon.conf
``` ini
[server]
host-name=rospi
#domain-name=local
#browse-domains=0pointer.de, zeroconf.org
use-ipv4=yes
use-ipv6=yes
#allow-interfaces=eth0
#deny-interfaces=eth1
check-response-ttl=no
#use-iff-running=no
#enable-dbus=yes
#disallow-other-stacks=no
#allow-point-to-point=no
#cache-entries-max=4096
#clients-max=4096
#objects-per-client-max=1024
#entries-per-entry-group-max=32
ratelimit-interval-usec=1000000
ratelimit-burst=1000

[wide-area]
enable-wide-area=yes

[publish]
#disable-publishing=no
#disable-user-service-publishing=no
#add-service-cookie=no
#publish-addresses=yes
publish-hinfo=yes
publish-workstation=yes
#publish-domain=yes
#publish-dns-servers=192.168.50.1, 192.168.50.2
#publish-resolv-conf-dns-servers=yes
#publish-aaaa-on-ipv4=yes
#publish-a-on-ipv6=no

[reflector]
#enable-reflector=no
#reflect-ipv=no
#reflect-filters=_airplay._tcp.local,_raop._tcp.local

[rlimits]
#rlimit-as=
#rlimit-core=0
#rlimit-data=8388608
#rlimit-fsize=0
#rlimit-nofile=768
#rlimit-stack=8388608
#rlimit-nproc=3
```

## 4. Passwordless SSH Login (From Your Laptop)

### 4.1 Check if you already have an SSH key

```bash
ls ~/.ssh/id_rsa.pub
```

If not:

```bash
ssh-keygen -t rsa -b 4096 -C "your@email.com"
```

### 4.2 Copy your key to the robot

```bash
ssh-copy-id ubuntu@rosbot.local
```

You should now be able to log in without a password:

```bash
ssh ubuntu@rosbot.local
```

## 5. ROS Humble Installation
Clone the ROS setup scripts repo on the robot, and run the humble setup script

```bash 
git clone https://github.com/Tiryoh/ros2_setup_scripts_ubuntu.git
cd ros2_setup_scripts_ubuntu
./ros2-humble-ros-base-main.sh
<enter sudo password>
```

## 6. Docker Installation

https://docs.docker.com/engine/install/ubuntu/

Before you install Docker Engine for the first time on a new host machine, you
need to set up the Docker `apt` repository. Afterward, you can install and update
Docker from the repository.

1. Set up Docker's `apt` repository.

   ```bash
   # Add Docker's official GPG key:
   sudo apt-get update
   sudo apt-get install ca-certificates curl
   sudo install -m 0755 -d /etc/apt/keyrings
   sudo curl -fsSL {{% param "download-url-base" %}}/gpg -o /etc/apt/keyrings/docker.asc
   sudo chmod a+r /etc/apt/keyrings/docker.asc

   # Add the repository to Apt sources:
   echo \
     "deb [arch=$(dpkg --print-architecture) signed-by=/etc/apt/keyrings/docker.asc] {{% param "download-url-base" %}} \
     $(. /etc/os-release && echo "${UBUNTU_CODENAME:-$VERSION_CODENAME}") stable" | \
     sudo tee /etc/apt/sources.list.d/docker.list > /dev/null
   sudo apt-get update
   ```

2. Install the Docker packages.

   To install the latest version, run:

   ```console
   $ sudo apt-get install docker-ce docker-ce-cli containerd.io docker-buildx-plugin docker-compose-plugin
   ```

3. Verify that the installation is successful by running the `hello-world` image:

   ```console
   $ sudo docker run hello-world
   ```

   This command downloads a test image and runs it in a container. When the
   container runs, it prints a confirmation message and exits.

  You have now successfully installed and started Docker Engine.

### 6.1 Add your user to the docker group (optional)
So you don't need sudo every time:

```bash
sudo usermod -aG docker $USER
newgrp docker
```
Log out and back in if docker still needs sudo.

## 7. SSH helper (optional)

append the following to your `.bashrc` or `.bash_profile` on the pi

```bash
# Start ssh-agent if not already running
if ! pgrep -u "$USER" ssh-agent > /dev/null; then
    eval "$(ssh-agent -s)"
fi

# Automatically add your key (if not already added)
SSH_KEY="$HOME/.ssh/id_ed25519"
if [ -f "$SSH_KEY" ] && ! ssh-add -l | grep -q "$SSH_KEY"; then
    ssh-add "$SSH_KEY" > /dev/null 2>&1
fi
```

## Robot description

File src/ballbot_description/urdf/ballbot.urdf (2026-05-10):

<?xml version="1.0" ?>
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
<robot name="ballbot_generated">
  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
  <link name="still_chassis_assm">
    <inertial>
      <origin xyz="0.0111808 0.000872117 0.0243927" rpy="0 0 0"/>
      <mass value="2.02918"/>
      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
    </inertial>
    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
  </link>
  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
  <link name="wheel_assm">
    <inertial>
      <origin xyz="1.70702e-10 1.09714e-10 0.00501766" rpy="0 0 0"/>
      <mass value="0.0495"/>
      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
    </inertial>
    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
  </link>
  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
  <joint name="front_left_wheel_joint_speed" type="continuous">
    <origin xyz="0.0680211 0.0783859 -0.0305" rpy="-1.5708 -1.4446e-29 9.71445e-17"/>
    <parent link="still_chassis_assm"/>
    <child link="wheel_assm"/>
    <axis xyz="0 0 1"/>
    <limit effort="10" velocity="10"/>
  </joint>
  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
  <link name="wheel_assm_2">
    <inertial>
      <origin xyz="1.09714e-10 1.70702e-10 -0.00501766" rpy="0 0 0"/>
      <mass value="0.0495"/>
      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
    </inertial>
    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
  </link>
  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
  <joint name="front_right_wheel_joint_speed" type="continuous">
    <origin xyz="0.0680211 -0.0776141 -0.0305" rpy="-1.5708 -1.53772 -1.03884e-14"/>
    <parent link="still_chassis_assm"/>
    <child link="wheel_assm_2"/>
    <axis xyz="0 0 1"/>
    <limit effort="10" velocity="10"/>
  </joint>
  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
  <link name="wheel_assm_3">
    <inertial>
      <origin xyz="1.09714e-10 -1.70702e-10 0.00501766" rpy="0 0 0"/>
      <mass value="0.0495"/>
      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
    </inertial>
    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
  </link>
  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
  <joint name="rear_left_wheel_joint_speed" type="continuous">
    <origin xyz="-0.0804789 0.0783859 -0.0305" rpy="-1.5708 1.5708 0"/>
    <parent link="still_chassis_assm"/>
    <child link="wheel_assm_3"/>
    <axis xyz="0 0 1"/>
    <limit effort="10" velocity="10"/>
  </joint>
  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
  <link name="wheel_assm_4">
    <inertial>
      <origin xyz="1.09714e-10 1.70702e-10 -0.00501766" rpy="0 0 0"/>
      <mass value="0.0495"/>
      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
    </inertial>
    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
  </link>
  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
  <joint name="rear_right_wheel_joint_speed" type="continuous">
    <origin xyz="-0.0804789 -0.0776141 -0.0305" rpy="-1.5708 -1.53772 3.02617e-15"/>
    <parent link="still_chassis_assm"/>
    <child link="wheel_assm_4"/>
    <axis xyz="0 0 1"/>
    <limit effort="10" velocity="10"/>
  </joint>
  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
  <link name="rplidar_a1_head">
    <inertial>
      <origin xyz="-0.0038177 0.00287126 -0.0126469" rpy="0 0 0"/>
      <mass value="0.0241839"/>
      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
    </inertial>
    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
  </link>
  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
  <joint name="lidar" type="fixed">
    <origin xyz="0.0855211 0.000385868 0.1315" rpy="-3.14159 -1.87145e-13 3.07126"/>
    <parent link="still_chassis_assm"/>
    <child link="rplidar_a1_head"/>
    <axis xyz="0 0 1"/>
    <limit effort="10" velocity="10"/>
  </joint>
  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
  <link name="mpu_9250">
    <inertial>
      <origin xyz="0.0072258 -0.0101825 -0.00197243" rpy="0 0 0"/>
      <mass value="0.00152565"/>
      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
    </inertial>
    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
  </link>
  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
  <joint name="imu" type="fixed">
    <origin xyz="-0.108479 0.0103859 0.005" rpy="-3.14159 -0 -3.14159"/>
    <parent link="still_chassis_assm"/>
    <child link="mpu_9250"/>
    <axis xyz="0 0 1"/>
    <limit effort="10" velocity="10"/>
  </joint>
  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
  <link name="webcam_glass">
    <inertial>
      <origin xyz="1.45304e-19 6.93889e-18 -0.000399182" rpy="0 0 0"/>
      <mass value="0.00160321"/>
      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
    </inertial>
    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
  </link>
  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
  <joint name="webcam" type="fixed">
    <origin xyz="0.158149 0.00263587 0.0556436" rpy="3.14159 1.5708 0"/>
    <parent link="still_chassis_assm"/>
    <child link="webcam_glass"/>
    <axis xyz="0 0 1"/>
    <limit effort="10" velocity="10"/>
  </joint>
  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
  <link name="cam_3_lens_front">
    <inertial>
      <origin xyz="-8.21704e-20 4.91901e-20 -8.50685e-05" rpy="0 0 0"/>
      <mass value="2.21049e-06"/>
      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
    </inertial>
    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
  </link>
  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
  <joint name="camera_module_lens" type="fixed">
    <origin xyz="0.103041 8.68467e-07 0.090095" rpy="3.14159 1.5708 0"/>
    <parent link="still_chassis_assm"/>
    <child link="cam_3_lens_front"/>
    <axis xyz="0 0 1"/>
    <limit effort="10" velocity="10"/>
  </joint>
  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
  <link name="base_footprint"/>
  <joint name="base_footprint_joint" type="fixed">
    <parent link="base_footprint"/>
    <child link="base_link"/>
    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
    <origin xyz="0 0 0.06449697" rpy="0 0 0"/>
  </joint>
  <link name="base_link"/>
  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
  <joint name="base_link_to_still_chassis_assm" type="fixed">
    <origin xyz="0 0 0" rpy="0 -0 0"/>
    <parent link="base_link"/>
    <child link="still_chassis_assm"/>
    <axis xyz="0 0 1"/>
    <limit effort="10" velocity="10"/>
  </joint>
  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
  <link name="imu_link"/>
  <joint name="imu_link_joint" type="fixed">
    <parent link="mpu_9250"/>
    <child link="imu_link"/>
    <origin xyz="0 0 0" rpy="3.14159 0 3.14159"/>
  </joint>

  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
  <link name="camera_sensor_mount"/>
  <joint name="webcam_to_sensor_mount_joint" type="fixed">
    <parent link="webcam_glass"/>
    <child link="camera_sensor_mount"/>
    <origin xyz="0 0 0" rpy="3.14159 1.5708 0"/>
  </joint>
  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
  <link name="camera_link_optical"/>
  <joint name="camera_optical_joint" type="fixed">
    <origin xyz="0 0 0" rpy="-1.5708 0 -1.5708"/>
    <parent link="camera_sensor_mount"/>
    <child link="camera_link_optical"/>
  </joint>
  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
</robot>

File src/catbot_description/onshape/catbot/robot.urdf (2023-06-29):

<robot name="catbot">
<link name="base_link"></link>
<joint name="base_link_to_base" type="fixed">
<parent link="base_link"/>
<child link="still_chassis_assm" />
<origin rpy="0.0 0 0" xyz="0 0 0"/>
</joint>
<link name="still_chassis_assm">
<visual>
<origin xyz="0 0 0" rpy="0 -0 0" />
<geometry>
<mesh filename="package://catbot_description/meshes/still_chassis_assm_visual.stl"/>
</geometry>
<material name="still_chassis_assm_material">
<color rgba="0.66987717125153911635 0.81712318213796708566 0.66602980483018847657 1.0"/>
</material>
</visual>
<collision>
<origin xyz="0 0 0" rpy="0 -0 0" />
<geometry>
<mesh filename="package://catbot_description/meshes/still_chassis_assm_collision.stl"/>
</geometry>
</collision>
<inertial>
<origin xyz="0.00027961412402240787278 0.0046876789374875821662 -0.0054409557585405705568" rpy="0 0 0"/>
<mass value="1.015668141636539179" />
<inertia ixx="0.0065127126032337098738" ixy="1.5566438777546685336e-07" ixz="3.6708728527239311778e-06" iyy="0.0025991819436423468752" iyz="6.1954470337197611722e-05" izz="0.0071648278899316356766" />
</inertial>
</link>

<link name="wheel_assm">
<visual>
<origin xyz="0 0 0" rpy="0 -0 0" />
<geometry>
<mesh filename="package://catbot_description/meshes/wheel_assm_visual.stl"/>
</geometry>
<material name="wheel_assm_material">
<color rgba="0.34876043041436377568 0.28454440741211711741 0.12249285133838178075 1.0"/>
</material>
</visual>
<collision>
<origin xyz="0 0 0" rpy="0 -0 0" />
<geometry>
<mesh filename="package://catbot_description/meshes/wheel_assm_collision.stl"/>
</geometry>
</collision>
<inertial>
<origin xyz="2.5876683183573441879e-09 -2.5321947361304500679e-09 -0.0043217676979120569353" rpy="0 0 0"/>
<mass value="0.054377782220193432439" />
<inertia ixx="1.7947780629583346784e-05" ixy="-3.8234084819748992999e-12" ixz="-1.6934852924892931359e-12" iyy="1.7621269066491268497e-05" iyz="-2.0136050748759971485e-12" izz="2.8213568549230894094e-05" />
</inertial>
</link>

<joint name="rr_wheel" type="revolute">
<origin xyz="-0.077614131532514007983 0.080478921592024327269 -0.030500000000000013212" rpy="-1.570796326794896558 0.67540343776289657463 -1.5707963267948956698" />
<parent link="still_chassis_assm" />
<child link="wheel_assm" />
<axis xyz="0 0 1"/>
<limit effort="1" velocity="20" />
<joint_properties friction="0.0"/>
</joint>

<link name="wheel_assm_2">
<visual>
<origin xyz="0 0 0" rpy="0 -0 0" />
<geometry>
<mesh filename="package://catbot_description/meshes/wheel_assm_2_visual.stl"/>
</geometry>
<material name="wheel_assm_2_material">
<color rgba="0.34876043041436377568 0.28454440741211711741 0.12249285133838178075 1.0"/>
</material>
</visual>
<collision>
<origin xyz="0 0 0" rpy="0 -0 0" />
<geometry>
<mesh filename="package://catbot_description/meshes/wheel_assm_2_collision.stl"/>
</geometry>
</collision>
<inertial>
<origin xyz="2.5876683388231371246e-09 -2.5321947856343332086e-09 -0.004321767697912089895" rpy="0 0 0"/>
<mass value="0.054377782220193432439" />
<inertia ixx="1.7947780629583370501e-05" ixy="-3.8234084811821872389e-12" ixz="-1.6934852959410392741e-12" iyy="1.7621269066491275274e-05" iyz="-2.013605069932675335e-12" izz="2.8213568549230904259e-05" />
</inertial>
</link>

<joint name="rf_wheel" type="revolute">
<origin xyz="-0.077614131532534658131 -0.068021078407976207081 -0.030499999999999957701" rpy="1.570796326794896558 5.0445758681405589749e-15 1.570796326794896336" />
<parent link="still_chassis_assm" />
<child link="wheel_assm_2" />
<axis xyz="0 0 1"/>
<limit effort="1" velocity="20" />
<joint_properties friction="0.0"/>
</joint>

<link name="wheel_assm_3">
<visual>
<origin xyz="0 0 0" rpy="0 -0 0" />
<geometry>
<mesh filename="package://catbot_description/meshes/wheel_assm_3_visual.stl"/>
</geometry>
<material name="wheel_assm_3_material">
<color rgba="0.34876043041436383119 0.28454440741211711741 0.12249285133838178075 1.0"/>
</material>
</visual>
<collision>
<origin xyz="0 0 0" rpy="0 -0 0" />
<geometry>
<mesh filename="package://catbot_description/meshes/wheel_assm_3_collision.stl"/>
</geometry>
</collision>
<inertial>
<origin xyz="2.5876683494035538817e-09 -2.5321947903698363363e-09 -0.0043217676979121003034" rpy="0 0 0"/>
<mass value="0.054377782220193432439" />
<inertia ixx="1.7947780629583370501e-05" ixy="-3.8234084811821831999e-12" ixz="-1.6934852949411820834e-12" iyy="1.7621269066491278662e-05" iyz="-2.0136050682372531551e-12" izz="2.8213568549230904259e-05" />
</inertial>
</link>

<joint name="rl_wheel" type="revolute">
<origin xyz="0.078385868467483257871 0.080478921592024507681 -0.030500000000000044437" rpy="-1.570796326794896558 -5.0445758681405660746e-15 1.5707963267948970021" />
<parent link="still_chassis_assm" />
<child link="wheel_assm_3" />
<axis xyz="0 0 1"/>
<limit effort="1" velocity="20" />
<joint_properties friction="0.0"/>
</joint>

<link name="wheel_assm_4">
<visual>
<origin xyz="0 0 0" rpy="0 -0 0" />
<geometry>
<mesh filename="package://catbot_description/meshes/wheel_assm_4_visual.stl"/>
</geometry>
<material name="wheel_assm_4_material">
<color rgba="0.34876043041436377568 0.28454440741211711741 0.12249285133838176687 1.0"/>
</material>
</visual>
<collision>
<origin xyz="0 0 0" rpy="0 -0 0" />
<geometry>
<mesh filename="package://catbot_description/meshes/wheel_assm_4_collision.stl"/>
</geometry>
</collision>
<inertial>
<origin xyz="2.587668269624447972e-09 -2.5321945322547953329e-09 -0.0043217676979121323957" rpy="0 0 0"/>
<mass value="0.054377782220193432439" />
<inertia ixx="1.7947780629583373889e-05" ixy="-3.8234084825756295263e-12" ixz="-1.6934852991867637216e-12" iyy="1.7621269066491278662e-05" iyz="-2.0136050681091290175e-12" izz="2.8213568549230907647e-05" />
</inertial>
</link>

<joint name="fl_wheel" type="revolute">
<origin xyz="0.078385868467507308077 -0.068021078407975985036 -0.030500000000000034028" rpy="-1.5707963267949118791 1.5703086100333234487 1.5707963267962468112" />
<parent link="still_chassis_assm" />
<child link="wheel_assm_4" />
<axis xyz="0 0 1"/>
<limit effort="1" velocity="20" />
<joint_properties friction="0.0"/>
</joint>


</robot>

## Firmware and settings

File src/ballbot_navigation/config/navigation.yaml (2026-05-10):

amcl:
  ros__parameters:
    use_sim_time: True
    alpha1: 0.2
    alpha2: 0.2
    alpha3: 0.2
    alpha4: 0.2
    alpha5: 0.2
    base_frame_id: "base_footprint"
    beam_skip_distance: 0.5
    beam_skip_error_threshold: 0.9
    beam_skip_threshold: 0.3
    do_beamskip: false
    global_frame_id: "map"
    lambda_short: 0.1
    laser_likelihood_max_dist: 2.0
    laser_max_range: 100.0
    laser_min_range: -1.0
    laser_model_type: "likelihood_field"
    max_beams: 60
    max_particles: 2000
    min_particles: 500
    odom_frame_id: "odom"
    pf_err: 0.05
    pf_z: 0.99
    recovery_alpha_fast: 0.0
    recovery_alpha_slow: 0.0
    resample_interval: 1
    robot_model_type: "nav2_amcl::DifferentialMotionModel"
    save_pose_rate: 0.5
    sigma_hit: 0.2
    tf_broadcast: true
    transform_tolerance: 1.0
    update_min_a: 0.2
    update_min_d: 0.25
    z_hit: 0.5
    z_max: 0.05
    z_rand: 0.5
    z_short: 0.05
    scan_topic: scan

amcl_map_client:
  ros__parameters:
    use_sim_time: True

amcl_rclcpp_node:
  ros__parameters:
    use_sim_time: True

bt_navigator:
  ros__parameters:
    use_sim_time: True
    global_frame: map
    robot_base_frame: base_link
    odom_topic: /odom
    bt_loop_duration: 10
    default_server_timeout: 20
    enable_groot_monitoring: True
    groot_zmq_publisher_port: 1666
    groot_zmq_server_port: 1667
    plugin_lib_names:
    - nav2_compute_path_to_pose_action_bt_node
    - nav2_compute_path_through_poses_action_bt_node
    - nav2_follow_path_action_bt_node
    - nav2_back_up_action_bt_node
    - nav2_spin_action_bt_node
    - nav2_wait_action_bt_node
    - nav2_clear_costmap_service_bt_node
    - nav2_is_stuck_condition_bt_node
    - nav2_goal_reached_condition_bt_node
    - nav2_goal_updated_condition_bt_node
    - nav2_initial_pose_received_condition_bt_node
    - nav2_reinitialize_global_localization_service_bt_node
    - nav2_rate_controller_bt_node
    - nav2_distance_controller_bt_node
    - nav2_speed_controller_bt_node
    - nav2_truncate_path_action_bt_node
    - nav2_goal_updater_node_bt_node
    - nav2_recovery_node_bt_node
    - nav2_pipeline_sequence_bt_node
    - nav2_round_robin_node_bt_node
    - nav2_transform_available_condition_bt_node
    - nav2_time_expired_condition_bt_node
    - nav2_distance_traveled_condition_bt_node
    - nav2_single_trigger_bt_node
    - nav2_is_battery_low_condition_bt_node
    - nav2_navigate_through_poses_action_bt_node
    - nav2_navigate_to_pose_action_bt_node
    - nav2_remove_passed_goals_action_bt_node
    - nav2_planner_selector_bt_node
    - nav2_controller_selector_bt_node
    - nav2_goal_checker_selector_bt_node

bt_navigator_rclcpp_node:
  ros__parameters:
    use_sim_time: True

controller_server:
  ros__parameters:
    use_sim_time: True
    controller_frequency: 20.0
    min_x_velocity_threshold: 0.001
    min_y_velocity_threshold: 0.5
    min_theta_velocity_threshold: 0.001
    failure_tolerance: 0.3
    progress_checker_plugin: "progress_checker"
    goal_checker_plugins: ["general_goal_checker"] # "precise_goal_checker"
    controller_plugins: ["FollowPath"]

    # Progress checker parameters
    progress_checker:
      plugin: "nav2_controller::SimpleProgressChecker"
      required_movement_radius: 0.5
      movement_time_allowance: 10.0

    # Goal checker parameters
    general_goal_checker:
      stateful: True
      plugin: "nav2_controller::SimpleGoalChecker"
      xy_goal_tolerance: 0.25
      yaw_goal_tolerance: 0.25
    # DWB parameters
    FollowPath:
      plugin: "dwb_core::DWBLocalPlanner"
      debug_trajectory_details: True
      min_vel_x: 0.0
      min_vel_y: 0.0
      max_vel_x: 0.4
      max_vel_y: 0.0
      max_vel_theta: 0.75
      min_speed_xy: 0.0
      max_speed_xy: 0.4
      min_speed_theta: 0.0
      # Add high threshold velocity for turtlebot 3 issue.
      # https://github.com/ROBOTIS-GIT/turtlebot3_simulations/issues/75
      acc_lim_x: 2.5
      acc_lim_y: 0.0
      acc_lim_theta: 3.2
      decel_lim_x: -2.5
      decel_lim_y: 0.0
      decel_lim_theta: -3.2
      vx_samples: 20
      vy_samples: 5
      vtheta_samples: 20
      sim_time: 1.7
      linear_granularity: 0.05
      angular_granularity: 0.025
      transform_tolerance: 0.2
      xy_goal_tolerance: 0.25
      trans_stopped_velocity: 0.25
      short_circuit_trajectory_evaluation: True
      stateful: True
      critics: ["RotateToGoal", "Oscillation", "BaseObstacle", "GoalAlign", "PathAlign", "PathDist", "GoalDist"]
      BaseObstacle.scale: 0.02
      PathAlign.scale: 32.0
      PathAlign.forward_point_distance: 0.1
      GoalAlign.scale: 24.0
      GoalAlign.forward_point_distance: 0.1
      PathDist.scale: 32.0
      GoalDist.scale: 24.0
      RotateToGoal.scale: 32.0
      RotateToGoal.slowing_factor: 5.0
      RotateToGoal.lookahead_time: -1.0
      
controller_server_rclcpp_node:
  ros__parameters:
    use_sim_time: True
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

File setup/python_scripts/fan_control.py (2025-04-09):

#!/usr/bin/env python3
# -*- coding: utf-8 -*-

"""
Controls the 52Pi PWM fan based on CPU temperature.

Reads CPU temperature from /sys/class/thermal/thermal_zone0/temp and adjusts
the fan speed connected to BCM pin 14 using PWM.
"""

import time
import RPi.GPIO as GPIO
import sys # For exiting gracefully

# --- Configuration ---
FAN_PIN = 14  # BCM pin used to control the fan PWM
PWM_FREQ = 100 # Hz - Frequency for PWM signal
CHECK_INTERVAL = 5 # seconds - How often to check temperature and adjust fan

# Temperature thresholds and corresponding duty cycles (in percent)
# Ensure keys are sorted from lowest temp to highest
# The fan runs at the speed defined for the highest threshold met.
# Example: 42°C meets the 40°C threshold, fan runs at 85%
#          47°C meets the 45°C threshold, fan runs at 100%
SPEED_MAP = {
    0: 0,      # Temperature below first threshold (e.g., < 40°C), fan is off
    40: 85,    # Temperature >= 40°C
    45: 100,   # Temperature >= 45°C
}

# --- Functions ---

def get_cpu_temp():
    """Read CPU temperature from system file and return in degrees Celsius."""
    try:
        with open("/sys/class/thermal/thermal_zone0/temp", "r") as f:
            temp_milli = int(f.read().strip())
        return temp_milli / 1000.0
    except (FileNotFoundError, ValueError, IOError) as e:
        print(f"Warning: Could not read CPU temperature: {e}", file=sys.stderr)
        # Return a safe default (e.g., high temp to ensure fan runs if sensor fails)
        # Or return None/raise exception if preferred error handling
        return 99.0 # Assume high temp on error to be safe

def get_fan_duty_cycle(temp):
    """Determine the fan duty cycle based on temperature and SPEED_MAP."""
    # Iterate through thresholds from highest to lowest
    # The first threshold met determines the speed
    sorted_thresholds = sorted(SPEED_MAP.keys(), reverse=True)
    for threshold in sorted_thresholds:
        if temp >= threshold:
            return SPEED_MAP[threshold]
    return 0 # Should not be reached if 0 threshold exists, but safe default

# --- Main Execution ---

pwm = None # Initialize pwm variable

try:
    # Setup GPIO
    GPIO.setwarnings(False) # Suppress warnings about channel usage
    GPIO.setmode(GPIO.BCM)
    GPIO.setup(FAN_PIN, GPIO.OUT)

    # Initialize PWM
    pwm = GPIO.PWM(FAN_PIN, PWM_FREQ)
    pwm.start(0) # Start with fan off

    print("Starting fan control loop...")
    while True:
        temp = get_cpu_temp()
        duty_cycle = get_fan_duty_cycle(temp)

        # Apply the new duty cycle
        pwm.ChangeDutyCycle(duty_cycle)

        # Optional: Log temperature and duty cycle
        # print(f"Temp: {temp:.1f}°C -> Fan Duty Cycle: {duty_cycle}%")

        # Wait for the next check
        time.sleep(CHECK_INTERVAL)

except KeyboardInterrupt:
    print("KeyboardInterrupt detected. Stopping fan and cleaning up.")
except Exception as e:
    print(f"An error occurred: {e}", file=sys.stderr)
finally:
    # Ensure cleanup happens on exit, error, or KeyboardInterrupt
    print("Cleaning up GPIO...")
    if pwm:
        pwm.stop()
    GPIO.cleanup()
    print("Fan control stopped.")

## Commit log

2023-06-25 replaced ssh agent with mounting .ssh (#12)
2023-06-27 create initial URDF (#13)
    * Created new `catbot_description` package with RosTeamWorkspace (RTW) `create-new-package` script.
    * Populated `catbot_description` package with RTW `setup-robot-description` script.
    * remove repo with example ros packages
    * replace repos file with empty one to fix ci
    * prevent colcon trying to build onshape dir and failing
    * Replaced example URDF via onshape-to-robot (O2R) generated URDF and imported STLs.
    * Created scripts to modify the generated URDF and move STLs to ROS standard mesh directories from template.
    * Added pre-commit in `catbot_description`
    * Fixed CI cpp linters failing due to no c/c++ files in package by swapping to [ros-tooling/action-ro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
    [65mm_wheel_with_high_friction_rubber_tire.stl, 6mm_hex_coupler.stl, aluminum_chassis_plate.stl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]
2023-06-29 Feature/gazebo (#23)
    * updated ros2_control urdf
    * package genreated by RTW
    * made pre-commit global
    * Fixed invisible gazebo model by exporting in package.xml
    ``` <export>
    <gazebo_ros gazebo_model_path="${prefix}/.." />
    </export>
    ```
    * color for gazebo
    * python intellisense update
    * remove annoying spellcheck
    * articulated robotics-based Robot State publisher
    * config for gazebo plugin accurate for catbot
    * update from onshape again
    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
    [catbot.urdf.xacro, catbot_macro.ros2_control.xacro, catbot_macro.xacro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]
2023-06-29 Feature/ros2 control sim (#27)
    * Use gazebo_ros2_control
    * approximate wheel collision as spheres to fix gazebo bug
    * align Gazebo and RViz model
    * make sim args work
    * rviz camera angle to follow robot
    * update README.md with simulation info
    * add catbot_simulation to CI linting
    [catbot.urdf.xacro, catbot_macro.ros2_control.xacro, catbot_macro.xacro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]
2023-10-25 Adopt Linorobot2 as a start
    * acknowledge linorobot2
    * Implement many linorobot2 features
    * rename to brobot
    * script for setting up robot
    * ignore files to be changed on robot
    * Update README.md
    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
    [4wd.urdf.xacro, 4wd_properties.urdf.xacro, base.urdf.xacro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]
2025-04-09 Update Documents, Setup Instructions, (#42)
    * fix permissions issues in container
    * add compressed image transport to dependencies so RVIZ works
    * made command_timeout.py executable permission to fix ros2 not finding it
    * add simple bedroom simulation map
    * add ubuntu setup instructions
    * update readme, todo - clarify new tennis goal
    * move deprecated/currently unused packages to archive
    * add OLED setup instructions
    * make scripts executable
    * create i2c group if doesn't exist
    * make not wait for ifaces on boot, update docs for oled
    * make script work regardless of working dir
    * don't rename oled python script when installing
    * try to fix python script
    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
    [65mm_wheel_with_high_friction_rubber_tire.stl, 6mm_hex_coupler.stl, aluminum_chassis_plate.stl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]
2025-04-20 Track tennis ball with opencv (#45)
    * try cleaning up dependencies
    * add blank ros2.repos
    * add v4l2 camera dependency
    * default to rplidar if env var isn't provided
    * undo having duplicate LIDAR nodes
    * put jsp in debug to see 'Got description'
    * make rviz in _viz use settings files
    * make map of upstairs
    * add .fastrtps.xml that fixes issue with RTPS payload size
    * automatically use custom fastrtps qos config
    * added linorobot2_hardware as firmware submodule
    * add teleop_twist_mux
    * try putting nav through twist_mux
    * get mux working for nav2 and joy
    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
    [ball_tracker_params_robot.yaml, laser.urdf.xacro]
2026-05-10 Set up LFS rules for STL/SO/HEX/XLSX, ignore Python noise + Yahboom ML models
2026-05-10 Vendor DOFBOT-SE source code, firmware, kinematics lib, datasheet
2026-05-10 Vendor DOFBOT-Pro and back-fill DOFBOT-SE ML models
    Drive downloads add the Pro hardware reference (URDF, STEP CAD,
    I2C protocol, expansion board pinout, servo datasheet), the Orin
    Super ROS 2 stack (dofbot_pro_ws/), legacy ROS 1 reference, and
    pretrained ML models for both Pro and (retroactively) SE.
    Three nested upstream repos submoduled at Yahboom's exact SHAs:
    CH341SER, ultralytics, ar_track_alvar. Yahboom's ultralytics
    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
2026-05-10 Refresh README for v2/BallBot, drop docs/TODO.md
    - BroBot → BallBot, fix broken catbot CI badge URLs
    - Reframe goal as pickleball ball-retrieval (post-rescope)
    - Note v2 hardware (Jetson Orin Nano Super, DOFBOT-SE arm, rpicam3)
    - Point at ARCHITECTURE.md, ROADMAP.md, and the GitHub Project
    for live progress instead of marking it in-repo
    - Delete docs/TODO.md — open items were either absorbed into
    ROADMAP milestones or extracted to side-quest issues #50-63
2026-05-10 Resurrect CAD-derived ballbot_descripition from onshape-description branch
    [a1_uart_bridge.stl, additional.xml, ballbot.urdf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]
2026-05-10 fix: rewire cmd_vel topology so sim matches real-robot firmware
    The sim cmd_vel chain had a feedback loop: twist_mux subscribed
    "navigation: cmd_vel" but also published /cmd_vel (via remap), and
    command_timeout sub+pub'd /cmd_vel as well. After a few non-zero
    msgs the loop saturated the topic and teleop input was drowned out.
2026-05-10 feat: add mass + CoG verification tool for URDF
    Walks the joint tree from a chosen root frame, transforms each link's
    inertial CoM into that root frame, and reports the mass-weighted CoG
    plus a per-link breakdown. Used to verify the onshape-derived URDF
    matches v1 robot mass within tolerance.
2026-05-10 fix: use CPU ray sensor for lidar so sim works without GPU
    The lidar was a <sensor type="gpu_ray">, which requires a working
    OpenGL context. In WSL2 / Docker without GPU passthrough the GPU
    sensor returns -inf for every range, so /scan looked alive but had
    no usable data. CPU <sensor type="ray"> works under the same
    gazebo_ros_ray_sensor plugin and produces real ranges.
    Changed in both additional.xml (the onshape-pipeline source) and
    the generated ballbot.urdf so they stay in sync until the next
    regeneration.
    [additional.xml, ballbot.urdf]
2026-05-10 fix(imu): publish sensor data in Z-up frame matching real chip
    mpu_9250's link frame inherits onshape's part-local axes (Z-down), so
    /imu/data was reporting accel.z = -9.79 m/s^2 stationary upright, and
    the orientation quaternion was a 180-degree rotation. That's mirrored
    from the physical chip on the real robot, which is mounted Z-up.
    Add an imu_link child of mpu_9250 that cancels the parent joint's
    (-pi, 0, -pi) flip, and move the gpu sensor onto imu_link with ROS 2
    plugin syntax (the old <frameName>/<bodyName>/<rpyOffset> tags were
    silently ignored by gazebo_ros_imu_sensor). The visual mesh stays on
    mpu_9250 unchanged, so RViz/Gazebo rendering is unaffected.
    Now publishes:
    frame_id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
    [additional.xml, ballbot.urdf]
2026-05-10 chore: remove old brobot_description, replaces with CAD ballbot description
    [4wd.urdf.xacro, 4wd_properties.urdf.xacro, base.urdf.xacro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]
2026-05-10 chore: renamed all 'brobot' to 'ballbot'
    [ball_tracker_params_robot.yaml]
2026-05-10 chore: rip out unused sensors - linorobot2 vestiges
2026-05-10 chore: remove catbot archive (migrated to ballbot)
    [65mm_wheel_with_high_friction_rubber_tire.stl, 6mm_hex_coupler.stl, aluminum_chassis_plate.stl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]
2026-10-27 persistent camera mapping
2026-10-27 fix(nav): check full footprint for collisions, stop planning through unknown
    Two changes aimed at the robot driving into obstacles that were correctly
    marked in the costmap.
    DWB used BaseObstacle, whose critic scores only the robot's CENTER point
    against the costmap, so a trajectory clipping an obstacle with the robot body
    is scored legal. Swapped to ObstacleFootprint, which checks the whole
    footprint. Its scale was also at the nav2 default 0.02 against path critics at
    24-32, leaving obstacle cost roughly 1600x weaker than path following; raised
    to 10.0.
    The planner had allow_unknown: true while the global costmap has
    track_unknown_space: true, so never-observed cells are NO_INFORMATION an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
2026-10-27 LLM-written skid-steer cal util script
2026-10-27 feat(nav): add my_room_bluebrook map, set min_laser_range
    Map of the upstairs room at Bluebrook, 5.9 x 4.0 m at 0.05 m/px, captured with
    slam_toolbox online_async. First map built on the corrected lidar frame and the
    gyro-driven EKF; walls close and corners are square.
    MAP_NAME now points at it instead of the first-floor bluebrook map.
    Also set slam_toolbox min_laser_range to 0.2 (the A1's blind zone). It
    defaulted to 0.0, which logged a warning every run and let near-field junk into
    the scan matcher.
2026-10-27 fix(dds): use asynchronous publish mode
    With RMW_FASTRTPS_USE_QOS_FROM_XML=1 the profile's publish mode applies, and
    Fast DDS defaults to SYNCHRONOUS. A remote subscriber over wifi (rosbag, RViz)
    then stalled the EKF loop by up to 0.84 s ("Failed to meet update rate").
2026-10-28 chore(firmware): bump submodule for CPR/track fix
    Picks up catbot f1c1afc (COUNTS_PER_REV halved, LR_WHEELS_DISTANCE 0.291)
    and 9bcaa6d (wheel joint names back to the plain *_wheel_joint used by
    ballbot.urdf).
2026-10-28 feat(tools): add forward dead-zone and drive-distance tests
    fwd_deadzone.py steps through low linear speeds and reports achieved vs
    commanded from wheel odometry. drive_dist.py drives until odometry reads
    0.5 m so the real distance can be measured; it exposed the 2x
    COUNTS_PER_REV error. yaw_cal.py now uses the current LR_WHEELS_DISTANCE.
2026-10-28 tune(nav): indoor speed cap, rotation dead zone, smaller inflation; trim RViz
    DWB: max_vel_x/max_speed_xy 0.4 -> 0.2, acc_lim_x 2.5 -> 1.0;
    min_speed_theta 0.3 with min_speed_xy 0.05 to keep in-place turns out of
    the skid-steer dead zone; acc_lim_theta 3.2 -> 10 so the sampling window
    can reach past the dead zone from rest.
    Costmaps: robot_radius 0.22 -> 0.13 (chassis half-diagonal 0.108),
    inflation_radius 0.55 -> 0.30, cost_scaling_factor 3 -> 5.
    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
2026-10-28 tune(nav): raise indoor speed cap to 0.3 m/s; yaw cal covers low rates
    With COUNTS_PER_REV fixed, 0.2 m/s really is 0.2 m/s (it was ~0.4 before),
    which felt sluggish. 0.3 leaves headroom under the ~0.41 m/s firmware RPM cap.
    yaw_cal.py now sweeps 0.1-0.4 rad/s to cover the rotation dead zone that
    min_speed_theta is set from.
2026-10-28 fix(nav): lower ObstacleFootprint critic scale 10 -> 0.5
    At 10, the footprint's inflation cost dwarfed every progress critic, so in
    narrow approaches (bathroom doorway) DWB preferred rotating in place over any
    forward motion: "Failed to make progress" with a valid plan, repeated through
    every recovery. Lethal footprints are still rejected outright and the planner
    already keeps the path off walls; this critic only needs to be a mild bias.
2026-10-28 change footprint padding to drive through doorways
2026-11-09 feat(cad): AI CAD workflow tooling + WIP Orin/PCB housing
    - onshape_step_sync.py: export/push/edges/mate between Onshape and build123d
    - parts/orin_housing.py: printable clamshell for YB-EVV01 + Orin with chassis, A1 and UART-bridge mounts
    - tools/dofbot_fit/: registration, interference checks and Onshape placement scripts
    - docs/ai-cad-workflow.md: FeatureScript vs code-CAD workflow; cad/context/ gitignored
    WIP: Onshape placement is wrong (PCB/Orin/lidar offsets, chassis centring); standoffs to be reworked.
    Claude-Session: https://claude.ai/code/session_01EWBRXN5e3bvBHoYtT7gGtc
2026-11-09 fix(cad): correct Onshape placement of Orin/PCB housing, A1 on kit stands
    - Absolute occurrencetransforms on a sub-assembly collapse its leaves; use relative moves on fresh inserts
    - orin_housing.step: geometry baked in place (no STEP placements), lidar standoffs -> kit 15+8 stands on pads
    - verify.py checks every Onshape leaf vs target (all 0.0000 mm); repair/reset scripts; API groups avoided
    Claude-Session: https://claude.ai/code/session_01EWBRXQRxjECg8uZhT74bUo
2026-11-09 fix(cad): full RPLIDAR A1 dev-kit stack (devboard + 15/8 mm stands) on cover pads
    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
2026-11-09 chore(cad): kit stack constant matches full stack (no geometry change)
    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
2026-11-09 fix(cad): v1 single-part A1 UART bridge in housing; includeNonSolids for composite parts
    - swap_bridge.py inserts the A1_UART-Bridge composite part (as v1 still_chassis_assm) at the bridge pose
    - place.insert / verify list instances with includeNonSolids (composite parts are omitted otherwise)
    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
2026-11-10 feat(cad): fastened mates replace Fix/Groups in housing + chassis; CAD workflow lessons doc
    - mates.py: one fixed ground part per assembly, origin-to-origin mates for same-studio parts, offset mate
    connectors (Z rotation + optional flipPrimary) for the rest; --chassis mates the housing to the plate
    - docs/ai-cad-workflow.md §8-12: repo/Onshape map, API-thrifty style, assembly lessons, Chrome usage, conventions
    - dofbot_fit README lists the newer scripts
    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
2026-11-10 feat(cad): lidar as v1 RPlidar A1 Base/Head sub-assemblies on 20+5 mm M2.5 standoffs
    - drop the A1 dev-kit board/stands; parts/lidar_standoffs.py -> out/lidar_standoffs.step (separate import)
    - check_lidar.py: holes land on pads, A1 lowest 5.5 mm above cover, no A1/cover/standoff/bridge interference
    - lidar_swap.py inserts Base/Head at the A1 pose and fastened-mates Base/Head/standoffs; verify.py covers them
    - doc: reuse v1 sub-assemblies, new STEP imports for new parts, fast interference checks
    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
2026-11-10 feat(cad): UART bridge on v1 rubber spacers + header pin slot; gold standoffs
    - bridge: 5 mm standoffs retired (Delete part in Onshape), 4 x v1 'm1.5 rubber spacer' mated under it
    - cover: 'bridge pin slot' Part Studio cut for the 7-pin header's THT tails
    - standoffs exported in brass (#FAB601) instead of random import colours
    - docs: never re-push a used STEP import, restore-point recovery, colours, v1 hardware
    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
2026-11-10 feat(cad): v2 housing stack on doc standoffs; lidar head to robot_assm
    - PCB on 6 x doc bn_3318 M2.5x10 M-F standoffs into floor inserts (2 mm bosses, Part Studio
    features on the imported base); whole stack +5 mm (RAISE), off the corner blocks
    - new cover import (orin_cover): +5 mm, lidar pad M2.5 inserts, bridge pin slot baked in
    - home-made STEP standoffs replaced by doc Bossard parts (Orin 4 x M2.5x20, lidar 20 + 5)
    - lidar head removed from the housing; robot_assm's v1 head + dof_lidar revolute re-pointed
    - Orin/PCB leaves detached by early leaf transforms re-synced in housing, chassis, robot
    - verify: all leaves 0.0000 mm; docs: hardware from the doc, detached leaves, implicit MCs
    Co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
2026-11-10 feat(cad): housing hardware, PCB on its standoff, base cleanup; done checklist
    - screws: A1 flange + Orin carrier 8 x M2.5x6, bridge 4 x M2x6, cover 4 x M3x8 (ISO 7045 pan head);
    base -> chassis plate 6 x M2.5x6 + thin nuts in still_chassis_assm
    - 18 heat-set inserts from a native 'heat-set inserts' Part Studio (Standard Content has none)
    - PCB fastened to board standoff 1 (mc pcb removed); hw mates use implicit connectors, connectors hidden
    - base: v1 pin pockets + corner M3 inserts filled; plate-screw clearance through the corner blocks
    - orin_housing.py only reads fan argv when run directly
    - docs: §13 done checklist + housing hardware BOM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
2026-11-10 feat(cad): v2b - PCB + Orin turned 180 so servo headers face the arm
    - orin_housing.py: BOARD_ROT; board holes, DOFBOT port windows and fan grille turned; grille clear of lidar pads
    - Onshape: boss sketches moved, new cover import, PCB + orin_assm re-inserted and mated to their standoffs,
    standoff / floor insert / Orin screw mates re-targeted; old cover + lidar_standoffs tabs deleted
    - orin_assm made rigid with an internal Group; PCB assembly's misplaced SOT-223 fixed in the element
    - verify, check_hw (+ chassis), robot copy: 0.0000 mm
    - docs: sub-assembly rigidity, per-context leaf positions, implicit-connector mate updates
    Claude-S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
2026-11-10 fix(cad): D23 <2> back on its sub-assembly in orin_assm; lessons on fixed groups and vendor faults
    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
